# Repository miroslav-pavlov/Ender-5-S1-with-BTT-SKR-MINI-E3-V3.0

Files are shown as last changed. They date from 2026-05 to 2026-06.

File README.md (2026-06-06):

# Creality Ender-5 S1 with BIGTREETECH SKR MINI E3 V3.0 board
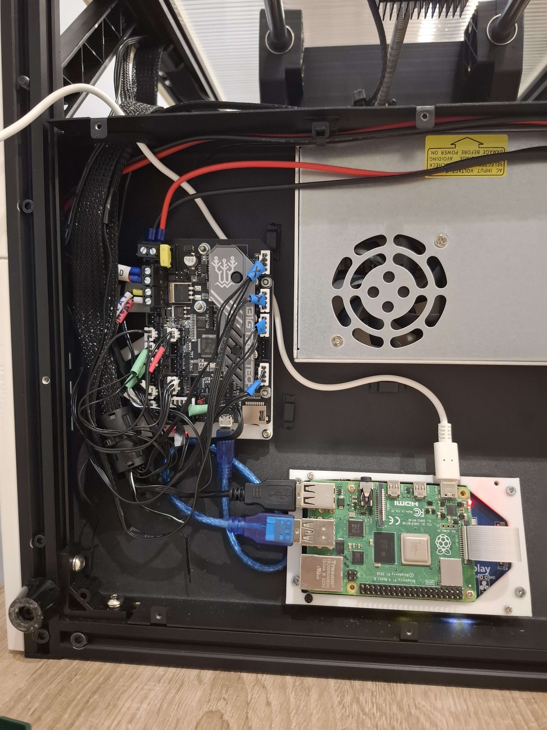
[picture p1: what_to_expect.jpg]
  

This is an old project I did after frying the original board and not finding an exact replacement. It's beautiful, isn't it?  

---
> [!WARNING]  
> - The SKR MINI E3 board as well as all other BTT boards don't support the proprietary printer screen and therefore need an RPi or another single-board computer capable of running Klipper for an online connection.
> - I did this project a couple of months ago and don't remember everything. I fact-checked all information again, but you should still take this guide with a grain of salt.

> [!NOTE]  
> - I compiled the needed pinouts into a spreadsheet which you can find in the files of this guide.
> - I used [this YouTube video](https://www.youtube.com/watch?v=VxCBDyvFSgA) for the pinout and advise you to double-check this guide's information with it.
> - I used [this pinout for the BTT board](https://github.com/bigtreetech/BIGTREETECH-SKR-mini-E3/blob/master/hardware/BTT%20SKR%20MINI%20E3%20V3.0/Hardware/BTT%20E3%20SKR%20MINI%20V3.0_PIN.pdf)
> - The printer head's board is the small black board nested behind the printer head where the other side of the big ribbon cable connects. It is mentioned multiple times in this guide.
---
## Materials needed
- [JST XH-2.54 pin connectors](https://www.aliexpress.com/item/1005008791163858.html)
- [A crimping tool](https://www.aliexpress.com/item/1005008645314178.html)
- A multimeter for verifying connections
- RPi or another single-board computer for Klipper
---
## 1. Connecting the 30-Pin Cable
> [!NOTE]
> - The big ribbon cable connects to a single 30-pin port on the original board but branches into 2 cables (24-pin and 6-pin). They are mapped next to each other in [the spreadsheet](Ender-5%20S1%20Cable%20Pinouts.xlsx)
> - You can find the orientation of your ribbon cable based on the white wire which is used for grounding and is also colored white in the [the spreadsheet](Ender-5%20S1%20Cable%20Pinouts.xlsx).
> - The BL Touch colour table is for cross-referencing with wiring tutorials for the BL Touch as the Ender-5 S1 one has all black cables.
> - The numbering of the motors and BL Touch pins (E1-E4, Y1-Y4, X1-X4 and BL1-BL5) is based on their location on the printer and is for easier verification of connections.
> - Use a multimeter to check if you did everything correctly.
### Steps
1. Cut the board end of the ribbon cable and remove a part of the plastic shielding.  
2. Use [the spreadsheet](Ender-5%20S1%20Cable%20Pinouts.xlsx) to crimp the cables with new connectors, then connect them to these ports:
- The **E-Motor** connects to port **EM**.
- The **BL Touch** connects to **Z-PROBE**. Unfortunately, I can't remember how I mapped the BL Touch, but I found this guide with the same model (ALT04) where the GND wires are the same color as in my spreadsheet, so I am inclined to believe him.
- The **thermistor** connects to port **TH0**. It has no polarity and can be connected both ways.
- The **hotend** and **part-cooling** fans are **FAN1** and **FAN2**. Use the fans table to map them to the board. They are named after the white ribbons with printed text on the printer head and from the inscriptions on the printer head's board. They share a common 24V wire so one of the fan connectors can have only 1 wire (Control) because it will get its power from the other one at the printer head's board.
- The **heat** connects to **E0**. It also has no polarity. All its right cables should be crimped together and all left ones also together. (Left and right should not be crimped together!)
- The **X-Stop** connects to **X-Stop**. It has no polarity.
- The **X-Motor** connects to port **XM**
## 2. Connecting the Y-Stop and Y-Motor
1. Cut the board end of the ribbon cable and remove a part of the plastic shielding.  
2. Use [the spreadsheet](Ender-5%20S1%20Cable%20Pinouts.xlsx) to crimp the cables with new connectors, then connect them to these ports:
- The **Y-Stop** connects to **Y-Stop**. It has no polarity.
- The **Y-Motor** connects to port **YM**.
## 3. Connecting the Z-Motor
1. Cut the board end of the ribbon cable and remove a part of the plastic shielding.  
2. Crimp the cables exactly like positioned on the ribbon. No need to switch their places.  
3. Connect the **Z-Motor** to port **ZAM**. You can also use port ZBM but may need to edit the printer.cfg.
## 4. Connecting the filament runout sensor
Try using [this reddit post](https://www.reddit.com/r/Ender3S1/comments/1685mug/ender_creality_filament_sensor_pinout/) to connect the sensor. If it doesn't work, try switching the signal and voltage :)
## 5. Connecting the bed
1. Remove a part of the plastic shielding.  
2. Connect the **chunky cables** to port **HB** with red being + and black being -  
3. Connect the **thin cables** to port **THB**. They have no polarity.
## 6. Connecting the power
1. You'll need to remove a couple of the windings from the ferrite core for the cable to reach the port. I was left with only 2 windings for the cable length to be sufficient.  
2. Connect the **power** to **POWER** with red being + and black being -
## 7. Flashing the board with Klipper
1. Follow [this guide](https://github.com/bigtreetech/BIGTREETECH-SKR-mini-E3/tree/master/firmware/V3.0/Klipper) on flashing Klipper. Both USB and UART can work. I personally chose USB.
## 8. Installing Klipper on the RPi 
1. Install Klipper on the RPi. If you've never done this before, the best way is using [KIAUH](https://github.com/dw-0/kiauh). That's what I personally use.
2. Use the **printer.cfg** from this guide's files as it has the right mappings for a BTT board inside an Ender-5 S1. Don't forget to change the mcu address and bltouch z_offset.
## 9. Mounting the RPi
1. You can use the mount from the description of [this YouTube video](https://www.youtube.com/watch?v=VSVQrhhNqhA).
2. Route all RPi cables through the cable hole on the back of the printer.
3. Optionally you can buy [this screen](https://www.aliexpress.com/item/1005008082461104.html) for [KlipperScreen](https://klipperscreen.readthedocs.io). It fits in the mount from the video and has my recommendations.
## 10. 3D Printing a mount for the board
1. Because the holes of the BTT board don't match the original one, I made a 3D printable mount which screws in the place of the old board. If you've fried the old board like me, you can leave the new one floating until the mount has been printed.
2. Use the picture from the start of the guide to correctly mount the board. You'll need a couple of small bolts and nuts or 3D print a couple of shafts to keep the board in place.
## 11. Connecting the board fan  
Connect the **board fan** to port **FAN2** without changing the connector.

You can finally close the back. Thanks for reading this guide. If you feel like I've helped you, you can leave a star :)

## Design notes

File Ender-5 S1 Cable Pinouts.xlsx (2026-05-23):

24 Pin Main Cable (Printer Head Side)
Ground | E 4 (2A) | E 2 (2B) | THER 1 | BL 1 BL 4 | BL 5 | BL 1 BL 4 | FAN1 Control | HEAT right | HEAT right | FAN1-2 VBB (24V) | HEAT left
Ground | E 3 (1A) | E 1 (1B) | BL 1 BL 4 | THER 2 | BL 2 | BL 3 | FAN1 Control | HEAT right | HEAT right | HEAT left | HEAT left
Cable | 24 Pin Main Cable (Board Side) |  |  |  |  |  |  |  |  |  |  |  |  |  |  |  |  |  |  |  |  |  |  |  | 6 Pin Side Cable
Group | Grounding |  | E-Motor |  |  |  | BL Touch | Thermistor |  | BL Touch |  |  |  |  | Fans |  | Heat Right |  |  |  | Heat Left | Fans | Heat Left |  | X-Stop |  | X-Motor
Pin | Ground | Ground | E 3 (1A) | E 4 (2A) | E 1 (1B) | E 2 (2B) | BL 1 BL 4 | THER 1 | THER 2 | BL 1 BL 4 | BL 2 | BL 5 | BL 3 | BL 1 BL 4 | FAN2 Control | FAN1 Control | HEAT R | HEAT R | HEAT R | HEAT R | Heat L | FAN1-2 VBB (24V) | Heat L | Heat L | PIN 1 | PIN 2 | X 1 (1A) | X 2 (2A) | X 3 (1B) | X 4 (2B)
Y-Stop And Y-Motor Cable
Group | Y-Stop |  | Y-Motor
Pin | PIN 1 (White cable) | PIN 2 | Y 1 (1A) | Y 2 (2A) | Y 3 (1B) | Y 4 (2B)
BL Touch Colours |  |  | Fans
5 | blue |  | Printer Name | Use | BTT Port
4 | red |  |  | Board | (FAN2)
3 | yellow |  | FAN1 | Hotend | (FAN1)
2 | black |  | FAN2 | Part Cool | (FAN0)
1 | white

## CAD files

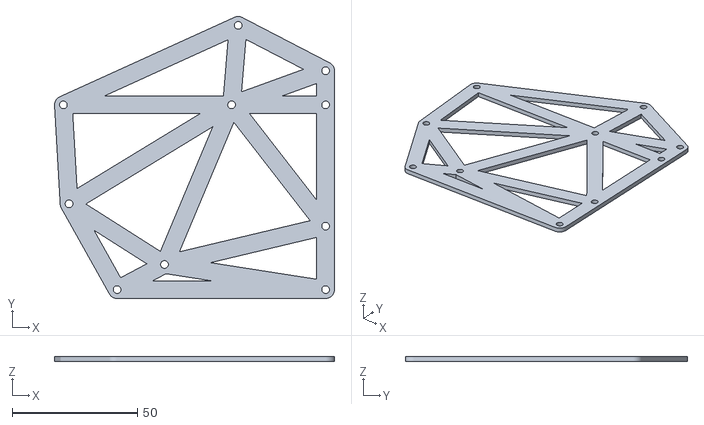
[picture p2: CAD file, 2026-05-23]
BTT SKR MINI E3 V3 Mount for Ender-5 S1.stl
112.0 x 112.8 x 2.00

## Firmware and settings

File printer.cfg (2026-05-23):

[include mainsail.cfg]
[virtual_sdcard]
path: /home/mirko/printer_data/gcodes
on_error_gcode: CANCEL_PRINT
[display_status]

# This file contains common pin mappings for the BIGTREETECH SKR mini
# E3 v3.0. To use this config, the firmware should be compiled for the
# STM32G0B1 with a "8KiB bootloader" and USB communication.

# The "make flash" command does not work on the SKR mini E3. Instead,
# after running "make", copy the generated "out/klipper.bin" file to a
# file named "firmware.bin" on an SD card and then restart the SKR
# mini E3 with that SD card.

# See docs/Config_Reference.md for a description of parameters.

[stepper_x]
step_pin: PB13
dir_pin: PB12
enable_pin: !PB14
microsteps: 16
rotation_distance: 40
endstop_pin: ^PC0
position_endstop: 220
position_max: 222
homing_speed: 80

[tmc2209 stepper_x]
uart_pin: PC11
tx_pin: PC10
uart_address: 0
run_current: 0.84
# stealthchop_threshold: 0

[stepper_y]
step_pin: PB10
dir_pin: !PB2
enable_pin: !PB11
microsteps: 16
rotation_distance: 40
endstop_pin: ^PC1
position_endstop: 220
position_max: 220
homing_speed: 80

[tmc2209 stepper_y]
uart_pin: PC11
tx_pin: PC10
uart_address: 2
run_current: 0.84
# stealthchop_threshold: 0

[stepper_z]
step_pin: PB0
dir_pin: !PC5
enable_pin: !PB1
microsteps: 16
rotation_distance: 8
endstop_pin: probe:z_virtual_endstop
position_max: 280
homing_speed: 20
second_homing_speed: 1
homing_retract_dist: 2.0

[tmc2209 stepper_z]
uart_pin: PC11
tx_pin: PC10
uart_address: 1
run_current: 0.84
# stealthchop_threshold: 0

[extruder]
step_pin: PB3
dir_pin: !PB4
enable_pin: !PD1
microsteps: 16
rotation_distance: 7.597
nozzle_diameter: 0.400
filament_diameter: 1.750
heater_pin: PC8
sensor_type: EPCOS 100K B57560G104F
sensor_pin: PA0
control: pid  # tuned for stock hardware with 210 degree Celsius target
pid_kp: 20.749
pid_ki: 1.064
pid_kd: 101.153
min_temp: 0
max_temp: 305
max_extrude_only_distance: 100

[tmc2209 extruder]
uart_pin: PC11
tx_pin: PC10
uart_address: 3
run_current: 0.650

[heater_bed]
heater_pin: PC9
sensor_type: EPCOS 100K B57560G104F
sensor_pin: PC4
control: pid  # tuned for stock hardware with 60 degree Celsius target
pid_kp: 66.566
pid_ki: 0.958
pid_kd: 1155.761
min_temp: 0
max_temp: 110

# Hotend fan
[heater_fan heatbreak_cooling_fan]
pin: PC7
heater:extruder
heater_temp: 60
fan_speed: 0.8

#Controller fan
[heater_fan controller_fan]
pin: PB15
# [fan_generic controller_fan]
# pin: PB15
# max_power: 1.0
# shutdown_speed: 1.0
# kick_start_time: 0.5
# initial_speed: 1.0

# Part cooling fan
[fan]
pin: PC6

[mcu]
serial: /dev/serial/by-id/usb-Klipper_stm32g0b1xx_2000080005504E5238363120-if00

[filament_switch_sensor filament_sensor]
pause_on_runout: true
switch_pin: !PC15

[safe_z_home]
home_xy_position: 123,83
speed: 200
z_hop: 10
z_hop_speed: 10

[bltouch]
sensor_pin: ^PC14
control_pin: PA1
x_offset: -13
y_offset: 27
z_offset: 2.087
speed: 10
stow_on_each_sample: true
samples: 4
sample_retract_dist: 2
samples_result: average
probe_with_touch_mode: true

[bed_mesh]
speed: 150
mesh_min: 3,28         # need to handle head distance with bl_touch
mesh_max: 205,218
mesh_pps: 3
probe_count: 5,5
fade_start: 1
fade_end: 10
fade_target: 0

# Many Ender 5 S1 printers appear to suffer from a slight twist
# in the X axis.  This twist can be measured, and compensated for
# using the AXIS_TWIST_COMPENSATION_CALIBRATE G-Code command.  See
# https://www.klipper3d.org/Axis_Twist_Compensation.html for more
# information.  This section provides the setup for this optional
# calibration step.
[axis_twist_compensation]
calibrate_start_x: 3
calibrate_end_x: 207
calibrate_y: 110

[printer]
kinematics: cartesian
max_velocity: 300
max_accel: 5000
max_z_velocity: 5
max_z_accel: 100
square_corner_velocity: 5.0

[board_pins]
aliases:
    # EXP1 header
    EXP1_1=PB5,  EXP1_3=PA9,   EXP1_5=PA10, EXP1_7=PB8, EXP1_9=<GND>,
    EXP1_2=PA15, EXP1_4=<RST>, EXP1_6=PB9,  EXP1_8=PD6, EXP1_10=<5V>

#*# <---------------------- SAVE_CONFIG ---------------------->
#*# DO NOT EDIT THIS BLOCK OR BELOW. The contents are auto-generated.
#*#
#*# [bed_mesh default]
#*# version = 1
#*# points =
#*# 	  0.357500, 0.196875, 0.101875, 0.071250, 0.139375
#*# 	  0.220000, 0.106875, 0.031250, -0.004375, 0.006250
#*# 	  0.160625, 0.036875, -0.032500, -0.059375, -0.036250
#*# 	  0.238125, 0.094375, 0.005000, -0.016875, -0.001250
#*# 	  0.331875, 0.223125, 0.093750, 0.142500, 0.140625
#*# x_count = 5
#*# y_count = 5
#*# mesh_x_pps = 3
#*# mesh_y_pps = 3
#*# algo = lagrange
#*# tension = 0.2
#*# min_x = 3.0
#*# max_x = 205.0
#*# min_y = 28.0
#*# max_y = 218.0

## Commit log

2026-05-23 Uploaded pinouts and mount
    Uploaded pinouts and mount
    [BTT SKR MINI E3 V3 Mount for Ender-5 S1.stl, Ender-5 S1 Cable Pinouts.xlsx]
2026-05-23 Uploaded printer config
    Uploaded printer config
    [printer.cfg]
2026-06-06 Improve README cable connection instructions
    Updated references to the spreadsheet for clarity and added links.
